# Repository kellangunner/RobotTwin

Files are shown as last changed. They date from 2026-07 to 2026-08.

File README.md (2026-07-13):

# RobotTwin

Digital twin of a 3-DOF desktop robotic arm (base yaw · shoulder pitch · elbow pitch),
designed to be 3D-printed on a Bambu Lab A1 Mini and driven by NEMA 17 steppers through
printed planetary/cycloidal gearboxes.

**Design stance:** linkage geometry is fixed and validated for printability
([docs/linkage-geometry.md](docs/linkage-geometry.md)); the **gearboxes are the independent
variables**. The interactive twin exists to answer: *which reduction, at what efficiency and
backlash, makes this arm work?*

## Quick start

```
cd web
npm install
npm run dev     # interactive twin at http://localhost:5173
npm test        # kinematics / drivetrain / trajectory unit tests
```

Pick each joint's drive type (direct 1:1 / planetary / cycloidal) and reduction ratio in the
left panel — efficiency, backlash, and torque caps are derived from the type — and watch torque
budgets, TCP backlash error, speed limits, move durations, and skipped-step predictions react.
Command poses via Cartesian target (analytical IK, elbow-up/down) or joint sliders.

## Layout

| Path | Contents |
|---|---|
| `config/robot.yaml` | Single source of truth for all robot parameters (SI-converted on load) |
| `docs/` | Decision records & subsystem docs |
| `src/` | **C++20 core library** — kinematics, drivetrain, dynamics, planning, collision ([docs](docs/cpp-core.md)) |
| `tests/` | Native C++ test suite (CMake/ctest), mirrors the web core's fixtures |
| `web/` | Interactive digital twin — React + React Three Fiber (math mirrors `src/`, WASM swap pending) |
| `cad/` *(planned)* | Fusion 360 generation scripts driven by the same YAML |

Build the C++ core:

```
cmake -S . -B build -G "Visual Studio 17 2022" -A x64
cmake --build build --config Release
ctest --test-dir build -C Release
```

See [CLAUDE.md](CLAUDE.md) for the full project charter and roadmap, and
[docs/digital-twin.md](docs/digital-twin.md) for the twin's architecture, equations, and
limitations.

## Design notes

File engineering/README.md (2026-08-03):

# Engineering — CAD generation

CAD is downstream of simulation: link geometry comes from
[config/robot.yaml](../config/robot.yaml) (90 / 120 / 120 mm, frozen per
[docs/linkage-geometry.md](../docs/linkage-geometry.md)); this folder turns it
into printable rigid members.

## Layout

```
engineering/
  fusion/robot_linkages/     linkage generator
    linkage_geometry.py        the parametric layer (pure Python, no Fusion):
                               every dimension, derived joint stacks, and ~50
                               analytic clearance self-checks
    robot_linkages.py          Fusion wrapper: replays the geometry and exports
  fusion/cycloidal_gearbox/  Fusion script that generates the 15:1 / 20:1 gearboxes
  gearboxes/                 gearbox design doc + per-ratio exports (see its README)
  gripper/                   parallel-jaw gripper: parametric layer + Fusion
                             script + design doc + exports (see its README)
  f3d/                       Fusion archive exports   (generated)
  step/                      STEP exports             (generated)
  stl/                       per-part STL exports     (generated)
```

## Verifying and running the generator

Before (or without) opening Fusion:

```
python engineering/fusion/robot_linkages/linkage_geometry.py   # clearance report
python python/audit_linkages.py                                # swept interference audit
```

The audit poses the assembly through full yaw, shoulder 0–180° and elbow
±150° and grid-samples for solid overlap between the printed members,
purchased hardware (motor bodies, screw heads, clamp bolt, the spinning
drive sleeves) and the reserved gearbox envelopes. Adjacent-link clearance is guaranteed mechanically;
whole-arm world collisions (e.g. folded forearm vs the base at extreme
combined poses) remain the twin's runtime collision layer, per
`collision:` in robot.yaml.

Then, in Fusion: UTILITIES → ADD-INS → Scripts and Add-Ins → Scripts → "+" →
select `engineering/fusion/robot_linkages/` → Run. It re-runs the self-checks
(refusing to build if any fail), creates a new Direct-Modeling design, and
writes `f3d/rt-arm-3dof_linkages.f3d` plus one STEP and one STL per part.

## The five printed members

| Part | Role | Bounding (mm) |
|---|---|---|
| `rt_base_pan` | Stationary base: hanging NEMA 17 mount + yaw bearing boss | Ø140 × 59 |
| `rt_shaft_coupling` | Printed coupling (base only): Ø25 bearing journal → Ø28 D-bore pinch body → bolt face. A standard part with its own STEP | Ø28 × 18 |
| `rt_yaw_column` | θ₁ output: low plate bolted to the coupling, clevis ears up to the shoulder axis (z = 90), gearbox mounting face | 76 × 68 × 76 |
| `rt_upper_arm` | Twin-beam clevis: shoulder hub → central beam → web → side beams → elbow clevis (axes exactly 120 mm apart) | 173 × 52 × 76 |
| `rt_forearm` | Elbow hub → beam → gripper interface plate; outer plate face is the TCP plane | 135 × 40 × 40 |

## Base: direct drive with a supported yaw axis

The base joint is driven directly by its NEMA 17 — no gearbox (the yaw axis
fights no gravity torque; the twin's torque governor paces yaw moves).

The motor is a 17HS4401 (42.3 sq × **40** long, 5 mm D-shaft ~23.5 mm): it
**hangs from the pan's 4 mm top plate** (inserted through the floor opening,
body floating above the floor — any 38–42 mm body fits), face bolted to the
plate's underside at z = 46. The arm's weight and overturning moment do
**not** ride on the bare motor shaft. Stack, bottom to top:

1. **Ø25 journal** (z 50.5–58.5) at the *bottom* of `rt_shaft_coupling`; the
   **6805-2RS (25×37×7)** slides on from this end and seats in the pan boss
   (outer race on a ledge at z 51.5, driver-access notches over the four
   motor screws double as head room).
2. **Ø28 pinch body** (z 58.5–69.5): printed D-bore for positive torque
   drive plus a split pinch squeezed by one M3 cross-bolt with a captured
   nut — *above* the bearing, so it is tightened after the coupling is on
   the shaft. Its bottom shoulder presses the bearing's inner race; weight
   goes body → inner race → outer race → boss, and the 6805 pairs with the
   motor's front bearing to resist moment as a spaced couple.
3. The **column plate** (Ø68 × 5) bolts down with 4 × M3 through counterbored
   holes into heat-set inserts in the coupling's top face. Everything on the
   column side near the yaw axis stays below z = 74.5 so the upper arm's
   shoulder hub swings clear through the full 0–180° shoulder range — this
   ceiling is what sizes the Ø30 hub (no hardware protrudes from it since
   the pinch clamp is gone).

The shoulder's drive-side ear disc reaches down to z = 52 and orbits the
stationary boss as the base yaws; the column carries two revolved relief
cuts (Ø47 to z 60.4, Ø52 to z 54.5) that keep it clear of the boss and the
motor screw heads while sparing the gearbox flange seat.

## Pitch joint architecture (shoulder and elbow identical)

- **Live shaft** (this rev, v5): the **8 mm shaft IS the torque path** and
  spins with the driven link. It stays a smooth rod — no flats, same
  68 mm cut as the dead-axle rev, so existing shafts are reused — and is
  grabbed at both ends by press/slip bores closed with **split pinches**
  (the base coupling's proven slit + M3-cross-bolt + captured-nut
  pattern).
- **Torque** flows: gearbox output → its **shaft-clamp extension** (Ø24.6
  pinch past the lid face) → shaft → the **arm hub's own pinch** (Ø30
  boss, slit on the −X side, two M3 cross-bolts) → arm.
- **Bearings live in the ears** now, not the hub: the +Y ear houses a
  **608** (outer race in a Ø22.2 pocket behind a Ø16 lip, inner race on
  the shaft); the drive ear houses a **6805** (Ø37.3 pocket from the
  gearbox face) riding the output extension's Ø25.05 seat. Structural
  loads still go through rolling bearings only.
- **Asymmetric clevis**: the drive ear sits at y 23.5–35.5 (9.75 mm
  further outboard than the +Y ear) so the output's pinch section has
  open tool access in the gap between ear and hub. The gearbox mounting
  face, Ø66 insert BCD, and M3 × 40 through-bolts are unchanged.
- **Axial retention**: both pinches fix the shaft; the +Y collar remains
  as a keeper snugged ~0.5 mm off the ear face (it must not rub the ear).
- **Torque-capacity caveat**: a pinch on smooth hardened rod is a
  friction joint. Degrease the shaft, torque the pinch bolts firmly, and
  treat slip under reversing loads as a real possibility — a drop of
  retaining compound (Loctite 638) in each bore is cheap insurance. This
  is the same interface the v2 design retired; it returns by explicit
  decision, traded for a serviceable joint that matches the purchased
  shaft stock.
- **Gearbox mounting face** (no enclosed drum — v1's drum could never admit
  the cartridge): the drive-side ear is a Ø76 disc whose outboard face
  carries **6 × M3 heat-set inserts on a Ø66 bolt circle**. The cycloidal
  cartridge (Ø76 × 36, see [gearboxes/README.md](gearboxes/README.md))
  bolts on with M3 × 40 through-screws from its back and carries its NEMA 17
  on its own back plate. Cartridge + screw heads + motor are audited as
  keep-out envelopes.
- The upper arm is a **twin-beam clevis**: the central beam ends at a
  derived hand-off station (x ≈ 62 for 120 mm links), a full-width web
  bridges to two side beams flanking the forearm's swing plane, and the
  forearm folds *between* them — this is what makes the full ±150° elbow
  range mechanically reachable (a single mid-plane beam cannot coexist with
  a forearm folded 150°).

## Fasteners

M3 everywhere. Every joint where a part bolts **to a printed member** gets
Ø4.6 × 6.5 pockets for **M3 × 5.7 heat-set inserts** (coupling top face ×4,
gearbox faces ×6 each, gripper plate ×4). Screws into a motor's own tapped
holes (NEMA mounts) and the table-mount holes are plain Ø3.4 clearance; the
base coupling's pinch bolt runs against a captured nut (the only pinch
left — the hub pinches died with the dead-axle rev).

## Gripper interface (forearm tip)

The 12 mm end plate's outer face is the TCP plane and the gripper's
mounting face (see [gripper/README.md](gripper/README.md)): a Ø10.5
through-bore on the TCP centerline registers the gripper's pilot boss and
passes its wiring (a bottom-edge notch feeds the harness under the beam),
and **4 × M3 heat-set inserts on a Ø16 BCD open on the OUTER face** — the
gripper's back plate bolts straight on with M3 × 8. (The earlier
inner-face insert pockets and T8-nut recess sat unreachable under the
forearm beam; the v2 gripper is SG-90 rack-and-pinion driven and uses no
screw hardware at all.) The fingertips reach `gripper_extent_mm` beyond
the TCP plane in the twin's collision model.

## Purchased hardware (BOM)

| Item | Qty | Where |
|---|---|---|
| 608 bearing (8×22×7) | 2 | one per +Y ear, inner race on the live shaft |
| 6805-2RS bearing (25×37×7) | 3 | yaw support + one per drive ear (on the gearbox output's seat) |
| 8 mm hardened steel shaft, cut to 68 mm | 2 | LIVE torque shafts — still smooth, no flats; both ends pinch-clamped (see docs/BOM.md) |
| 8 mm shaft collar | 2 | one per pitch joint, +Y keeper (snug 0.5 mm off the ear) |
| M3 × 20 + nut | 4 | arm-hub pinch bolts, two per hub |
| M3 × 16 + nut | 2 | gearbox-output pinch bolts, one per output |
| SG-90 micro servo | 1 | gripper actuation (lantern pinion + hobbed racks) |
| NEMA 17 17HS4401 (42.3 sq, 40 long) | 3 | one per joint, per config |
| M3 × 5.7 heat-set inserts | 20 | coupling (4), gearbox faces (2×6), gripper plate (4) — the gripper body adds its own |
| M3 nuts | 1 | coupling pinch cross-bolt |
| M3 screws | — | all connections |

## Assembly order

Motor in from below → face screws through the boss notches → pan to table →
6805 into the boss pocket → coupling (journal down) through the bearing onto
the D-shaft → tighten its pinch bolt → column plate bolted down into the
coupling's inserts → 608 pressed into the +Y ear, 6805 pressed into the
drive ear's outboard pocket → arm between the ears, shaft in from the +Y
side through the ear 608 and the hub bore (hub pinch loose) until ~10 mm
protrudes past the hub on the −Y side → gearbox cartridge (bench-assembled,
motor on its back) offered up: its extension slides through the drive-ear
6805 and its bore swallows the shaft end; 6 × M3 × 40 from the gearbox back
into the ear-disc inserts → tighten the OUTPUT pinch bolt (tool access in
the ear-to-hub gap), then the two HUB pinch bolts, then the +Y collar
0.5 mm off the ear face. Every fastener is reachable at its step.

## Assumptions and limitations

- Direct-modeling generator: no Fusion timeline; `linkage_geometry.py` is the
  parametric layer (geometry read from `robot.yaml` at run time) and refuses
  to build if any clearance self-check fails.
- No fillets/chamfers yet — add stress relief at the beam-to-ear transitions
  before printing structural versions.
- The gearbox interface (Ø76 face, Ø66 bolt circle, 6805 pocket, extension
  diameters, pinch length) is a mirrored contract with
  `cycloidal_gearbox.py` — the `GBX_*` constants here and the `ext_*` yaml
  keys there must move together.
- The pinch-on-smooth-shaft couplings are friction joints; their torque
  limit is unproven and lower than the retired sleeve-flat form lock (see
  the gearboxes README's open issues and the caveat above).
- Print settings assumed by the mass model: PETG, ~30 % infill.

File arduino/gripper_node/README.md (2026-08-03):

# Gripper node

An Arduino Uno driving the SG-90 parallel-jaw gripper, independent of the ESP32
that runs the arm.

## Why it is a separate board

The gripper was always the least-coupled subsystem in the robot — no kinematics,
no trajectory, no homing, no torque governor, no place in the firmware's state
machine. Giving it its own MCU therefore costs almost nothing and buys three
things:

- **Power isolation.** A stalled SG-90 pulls ~650 mA. That is precisely the
  transient that browns out a board generating step pulses, and it was already
  the documented brown-out risk on the shared 5 V rail.
- **Correct logic levels.** An SG-90 expects ~5 V pulses. The ESP32 drives
  3.3 V — it works, but with no margin. The Uno's 5 V output is right.
- **A timing consumer removed** from a board running a 1 kHz step engine.

## Two ways to command it, last one wins

- **The knob on A0.** Needs no computer at all, which is what makes it the
  calibration tool. It only takes control once it moves past a small deadband,
  so ADC jitter cannot silently steal the jaws back from a running script.
- **`G <mm>` / `GRIP <mm>` / `R` on either serial port.** USB from a host, or the
  one-way relay from the ESP32 so a scripted move can grip mid-sequence. A
  command re-anchors the knob and takes control back from it.

The onboard LED is solid while the jaws hold, blinks while they move, and is off
when the servo is slack.

Nothing is driven at power-on. The jaws are only *assumed* to sit at
`boot_opening_mm`, so the first deliberate command is what energizes the servo —
that way a power-on cannot lurch the mechanism.

## Where the numbers come from

None of the calibration lives in this sketch. `scripts/gen_gripper_config.py`
reads the `gripper:` block of `config/firmware.yaml` before every build and
emits `src/gripper_config_gen.hpp`, so a pulse-width change is a config edit plus
a reflash — never a code change.

The slew limiting and the opening → pulse-width mapping are not written here
either. They come from `rt::GripperAxis` in `src/hardware/gripper.cpp`, compiled
straight out of the repo core — the same class the twin, the native tests, and
the ESP32 use. That is deliberate: the ESP32 predicts when the jaws land without
ever hearing back from this board, which only works because both run identical
math on identical numbers.

## Pins

| Pin | Function |
| --- | --- |
| D9  | Servo signal (orange). Must be D9 or D10 — the `Servo` library owns Timer1 |
| A0  | Potentiometer wiper; the pot's ends go to Uno 5 V and GND |
| D2  | `SoftwareSerial` RX ← ESP32 GPIO 13 through 1 kΩ |
| D3  | Reserved. Unwired — a future return path would use it |
| D13 | Onboard status LED |
| USB | Host: power, uploads, and the console at 115200 |

D2 rather than D0 because the Uno's hardware UART is wired to its USB chip;
putting the relay there would fight the console and break sketch uploads.

Servo power is a bench supply at 5.0 V with a 1 A limit, with a 470–1000 µF
electrolytic at the servo connector. It shares only a ground with the Uno and
the ESP32. Full wiring, including what not to do with the Uno's barrel jack, is
in [docs/wiring-and-bringup.md](../../docs/wiring-and-bringup.md).

## Build

```bash
pio run -t upload
```

```bash
pio device monitor
```

Commands at the console: `G <mm>`, `GRIP <mm>`, `R`. Traffic arriving on the
relay link is echoed here too — with a one-way link, that echo is the only
evidence the ESP32 is reaching this board.

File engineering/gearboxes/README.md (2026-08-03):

# Cycloidal gearboxes — 15:1 and 20:1 (v3 pinned casing, v5 live-shaft output)

Single-stage cycloidal reducers for the pitch joints (shoulder, elbow): a
**plain Ø76 × 36 mm casing in two flat printed halves** — a *cup* (motor
plate + outer wall) and a *lid* (the mounting flange) — **held together and
registered by the Ø6 × 25 steel ring dowels themselves**, which run through
the entire cup and seat in blind holes in the lid. Six M3 × 40 screws from
the gearbox back clamp cup + lid + linkage ear in one stack: they are the
case closure *and* the mounting. The lid face bolts to the linkage's
drive-side ear disc (Ø76, 6 × M3 heat-set inserts on a **Ø66 bolt
circle**). Since the live-shaft rev (v5) the 8 mm joint shaft IS the torque
path: past the lid face the output's Ø22 hub becomes the **shaft-clamp
extension** — a Ø25.05 seat carrying the drive ear's **6805** support
bearing, then a Ø24.6 **split pinch** that clamps the smooth shaft, whose
other end the arm hub grabs with its own pinch. Only the OUTPUT changed for
v5: **cup, lid, discs, cam, and pins are identical to the dead-axle prints —
do not reprint them.** Both ratios share every dimension except the disc
lobe count and cam eccentricity, so the twin's gearbox trade study
(`gearboxes.shoulder.ratio` in [config/robot.yaml](../../config/robot.yaml))
maps 1:1 onto hardware swaps.

**Single source of truth:** every design-specific number lives in
[gear_parameters.yaml](gear_parameters.yaml). The Fusion generator
([engineering/fusion/cycloidal_gearbox/](../fusion/cycloidal_gearbox/)) and
the validator (`python/validate_cycloid.py`) both parse it — edit the yaml,
re-run both, never edit constants in the scripts.

## Why v3 (the v2 print failed)

v2's monolithic housing was clever and unprintable-in-practice: necked
body, groove-wrapped pins, a pinch clamp fed through a wall tunnel — and
the discs jammed ("too large") because the 0.15 mm profile clearance
vanished under real FDM tolerances. v3 is the simple version:

| | v2 (monolith) | v3 (pinned sandwich) |
|---|---|---|
| Casing | one Ø62/Ø59 necked body, hairline OD slits | two flat Ø76 halves, no supports-critical features |
| Ring dowels | grooves wrapped past the pin equator | free-standing, **through the cup + 6.5 mm into the lid**, double shear, fully captive |
| Case closure | — (monolith) | the ring dowels register the halves; the 6 mount screws clamp them |
| Mount screws | M3 × 10 at the flange, hex key threaded past the body | M3 × 40 through-bolts from the back — nothing to sneak past |
| Disc-to-box fit | 0.9 mm to a grooved ring bore | **4.4 mm to a plain Ø62.5 interior** — the box cannot bind the disc |
| Profile clearance | 0.15 mm (jammed as printed) | **0.25 mm, yaml-tunable**, plus a numeric assembled-mesh sweep in the validator |
| Shaft coupling | split pinch + captured nut + access tunnel | **drive sleeve**: the output's flats plug straight into the arm hub — the shaft is a static, torque-free axle (no flat, no grub screw, no pinch) |
| Parts per gearbox | 4 printed | 5 printed, every one trivial to print |

## How it works

Fixed-ring, rotating-output cycloidal drive. Ratio = Zc (lobes), reversing:

1. The motor's 5 mm D-shaft spins the **eccentric cam** (`rt_cyc*_cam`): two
   Ø15 journals offset ±e, 180° apart, each carrying a **6802-2RS** bearing.
2. Two identical **cycloid discs** (`rt_cyc*_disc`, clocked half a lobe
   apart) wobble on the bearings; their lobes walk around **Zp = Zc + 1
   Ø6 × 25 steel dowel pins** standing free between the casing halves —
   pressed through the cup's bottom (flush at the back face), located in
   the lid's blind holes, loaded in double shear. The pin pattern is
   clocked (11.25° / 0°) so the cup's press holes clear the NEMA screws.
3. Per cam revolution each disc creeps back one lobe pitch: rotation −1/Zc.
   Six more **Ø6 × 25 dowels** pressed 11.7 mm into the **output flange**
   (`rt_cyc*_output`) ride in oversized disc holes (Ø = pin + 2e + 0.3) and
   carry the slow rotation out. The flange's Ø22 hub passes out through
   the lid's Ø25.85 face bore — sized so the **whole extension assembles
   through it** — and continues past the lid face as the **shaft-clamp
   extension**: first a Ø25.05 seat that rides the **6805 bearing housed
   in the drive ear** (this carries the joint's −Y structural load), then
   a Ø24.6 body ending in a **split pinch** — slit open at the tip, one
   M3 cross-bolt with a captured nut — that clamps the live 8 mm shaft.
   The shaft slips ~19.5 mm into the extension's Ø8.35 bore; torque goes
   output → pinch → shaft → the arm hub's own pinch. The drive-ear 6805,
   not the lid, locates the output radially.

Two discs on opposite eccentrics balance the wobbling mass and split the
tooth load; the disc profile is the exact conjugate envelope of the pin set
(generated by simulated hobbing in the Fusion script).

## Parameters

Shared: pin circle R = 28, every pin a Ø6 × 25 steel dowel, disc thickness
6, disc bore Ø24.2 (6802 OD + 0.2), output pins on a Ø36 BCD, profile print
clearance 0.25 mm radial (yaml: `profile_print_clearance` — tune on a test
disc), casing Ø76 with a Ø62.5 interior.

**Steel-pin hole fits are printer-specific — calibrate them.** FDM prints
holes undersize, by an amount that depends on your machine, material, speed,
and cooling, so the pin-hole diameters are modeled *over* nominal to
compensate and are yaml parameters, not fixed numbers
(`external_pin_hole_clearance`, `output_pin_hole_clearance`,
`ring_pin_lid_clearance`, all diametral, added to Ø6). The defaults aim for
a *slip/light* fit retained with adhesive — the most repeatable result
across printers — not a bare interference press, which is what jammed on the
first attempt. The cam's D-bore on the motor's 5 mm shaft is the same story
and is yaml too (`motor_bore_clearance`, `motor_flat_clearance`) — the Ø5.2
first print needed a hammer. See the calibration step under Printing before
committing a full set of dowels.

| | 15:1 | 20:1 |
|---|---|---|
| Disc lobes Zc / ring pins Zp | 15 / 16 | 20 / 21 |
| Eccentricity e | 1.0 mm | 0.8 mm |
| Trochoid coefficient λ = e·Zp/R | 0.57 | 0.60 |
| Disc root / tip radius | 23.75 / 25.75 | 23.95 / 25.55 |
| Min convex profile curvature (vs Ø6.5 cutter) | 6.6 mm ✓ | 5.0 mm ✓ |
| Assembled mesh clearance (full cam sweep) | 0.25 mm ✓ | 0.25 mm ✓ |
| Radial mesh engagement 2e | 2.0 mm | 1.6 mm |
| Disc output holes (6×) | Ø8.30 | Ø7.90 |
| Output torque @ 0.45 Nm × η 0.60 | **4.05 Nm** | **5.40 Nm** |
| Output speed @ 600 rpm input | 40 rpm (240°/s) | 30 rpm (180°/s) |
| Shoulder gravity margin, 100 g payload (1.17 Nm) | ×3.5 | ×4.6 |
| Shoulder gravity margin, 2 kg payload (5.64 Nm) | ×0.72 ✗ | ×0.96 ✗ |
| Cam bearing load (per 6802, C₀ ≈ 1.27 kN) | ~135 N | ~170 N |
| Peak ring / output pin load (steel) | ~36 / ~75 N | ~37 / ~100 N |

Neither ratio statically holds the 2 kg *maximum* payload at full horizontal
reach — that corner of the envelope stays governed by the twin's torque
governor, exactly the trade the digital twin exists to explore. 20:1 gets
within 4 % of it.

## Axial stack (z from the cup's back face, 36 mm to the mounting plane)

```
z  0.0 -  5.0   cup bottom: Ø22.5 pilot recess (2.2 deep), Ø14 shaft bore,
                4x M3 counterbored from inside (heads z 1.5..4.5),
                Zp x Ø6.1 ring-dowel holes, back-chamfered (flush at z 0)
z  0.0 - 25.0   Ø6 x 25 steel ring dowels: through the cup, 6.5 mm into
                the lid's blind holes — they pin the casing together
z  5.0 - 18.5   cup wall, plain Ø62.5 bore (disc reach Ø53.7: 4.4 mm air)
z  5.5 - 11.5   disc A on cam journal +e (bearing 6802)
z 12.0 - 18.0   disc B on cam journal -e, clocked half a lobe
z  5.7 - 30.7   Ø6 x 25 steel output pins (blind holes end z 30.9)
z 18.5 - 36.0   lid: bore Ø48 to z 31.9 (flange plate spins inside),
                then Ø25.85 face bore (the extension assembles through
                it); face flush on the ear disc
z 19.0 - 31.4   output flange plate Ø46 (motor-shaft pocket to z 26 inside)
z 28.0 - 57.75  shaft bore Ø8.35: slip fit, closed onto the shaft by the pinch
z 31.4 - 36.0   output hub Ø22: spins free inside the lid face bore to z 36
z 36.0 - 43.0   Ø25.05 seat: the drive ear's 6805 rides here (pocket depth 7)
z 43.0 - 57.75  Ø24.6 extension body through the ear's Ø27 shoulder, ending
                in the SPLIT PINCH (z 48.75-57.75: slit open at the tip,
                M3 cross-bolt at z 53.25, captured nut) that clamps the
                shaft in the open gap before the arm hub (face at z 58.5)
```

The motor's shaft (max 25 mm) ends inside the flange plate's Ø8.6 pocket
(ceiling z 26); the live joint shaft enters from the far ear through that
ear's 608 and the arm hub's pinch bore, and its tip stops at z 38.25 —
2.25 mm shy of the lid face, ~19.5 mm deep in the extension bore, fully
covering the pinch. The existing 68 mm shafts are reused unmodified.

## Assembly

1. M3 × 8 from inside the empty cup into the motor's threads (pilot boss in
   the recess). Slide the cam onto the D-shaft; the 6802s press onto its
   journals.
2. Disc A over bearing A, disc B over B — the output-hole pattern self-jigs
   the half-lobe clocking.
3. Seat the Zp ring dowels in the cup holes until flush at the back (a dab
   of adhesive per the calibration note unless you dialled in a true press);
   they thread through the meshed disc valleys — wiggle the discs if one
   hangs. The back chamfer starts them straight.
4. Seat the six output dowels in the flange's blind holes (same fit); feed
   the pin cage through both discs.
5. Lower the lid over the extension and onto the dowel tips (the blind
   holes are the jig). The cartridge is now complete but unclamped.
6. Press the 608 into the +Y ear and the 6805 into the drive ear's
   outboard pocket. Set the arm between the ears and slide the 8 mm shaft
   in from the +Y side, through the ear 608 and the hub's pinch bore
   (pinch loose), until ~10 mm protrudes on the −Y side.
7. Offer the cartridge up to the drive ear: the extension tip (Ø24.6)
   passes through the 6805, its Ø25.05 seat presses lightly into the
   bearing bore, and the Ø8.35 bore swallows the shaft end. Run the six
   M3 × 40 from the gearbox back through everything into the ear-disc
   inserts (snug Ø3.2 holes center the casing). Tighten the OUTPUT pinch
   bolt in the ear-to-hub gap, then the arm hub's two pinch bolts, then
   fit the +Y collar 0.5 mm off the ear face. Degrease the shaft first —
   both couplings are friction clamps.

## Printing (Bambu A1 Mini, PETG, ≥4 perimeters, 50 %+ infill)

**Calibrate the dowel holes first.** Print a scrap coupon with a row of
holes at Ø6.0, 6.1, 6.2, 6.3, 6.4 and try a real dowel in each. Pick the
smallest that accepts the pin with firm hand/light-tap pressure (no
splitting) — that diameter minus 6.0 is your `*_hole_clearance` value; set
the three yaml keys and re-run the generator. The stock values are
print-verified on an A1 Mini: cup and lid press perfectly at +0.10
(bed-face holes shrink only ~0.1 mm); the flange runs +0.15 because its
+0.05 first print was too tight to seat. Note the cam's vertical D-bore
shrinks much more than these bed-face holes — its fit is separate
(`motor_bore_clearance`). If you raise the cup value, the NEMA counterbore
clearance check caps it ≈ +0.27 on the 21-pin ring. If you land on a slip fit, that is fine — a drop of
cyanoacrylate or retaining compound in each hole holds the pin far more
repeatably than a bare press, and the ring pins are captive in the sandwich
regardless. The holes carry a back-face (printed-bottom) chamfer to swallow
the elephant's-foot lip and start the pin straight.

- Cup: back face down, wall up — no supports.
- Lid: mounting face down — the internal Ø25.85→Ø48 step is an annular bridge
  ~4.6 mm up; enable supports for it or accept the bridge (it's a
  non-bearing ceiling).
- Discs: flat, no supports. Print ONE first and confirm it drops over the
  assembled pins and rocks freely — the 0.25 mm profile clearance is
  yaml-tunable if your printer runs tight or loose.
- Cam: bore vertical, no supports. Journals sized Ø15.05 — sand to a light
  press on the 6802s. The D-bore is modeled Ø5.35 with the flat 0.2 proud
  (`motor_bore_clearance` / `motor_flat_clearance`) so it *slides* onto the
  motor shaft — the flat drives, the bore only locates.
- Output flange: plate face down (pin holes open at the bed), sleeve up, no
  supports — the pin holes print at their calibrated Ø with the lead-in
  chamfer at the bed, the drive flats print as clean vertical walls, and
  the Ø2.5 lock pilot is a short horizontal hole that needs no support.

## Purchased hardware (per gearbox)

| Item | Qty | Where |
|---|---|---|
| Ø6 × 25 mm steel dowel pin | Zp + 6 (22 / 27) | Zp casing/ring pins + 6 output drive pins |
| 6802-2RS bearing (15 × 24 × 5) | 2 | eccentric cam journals |
| M3 × 8, socket head | 4 | cup → motor threads (heads inside) |
| M3 × 40, socket head | 6 | through the casing → ear-disc heat-set inserts |

(The 608s, 8 mm axle, outboard collar, and the heat-set inserts belong to
the joint/linkage BOM. The axle is static and torque-free: cut to length,
no ground flat, no grub screw — the drive sleeve couples the output
straight to the arm hub.)

## Open issues (before printing structural versions)

1. **Pinch-on-smooth-shaft torque path is unproven — and it is a friction
   joint, not a form lock.** The 20:1 output can deliver 5.4 Nm; a PETG
   split pinch plus a press bore on polished hardened rod plausibly holds
   a few Nm when fresh and loses preload to plastic creep over time.
   Mitigations, in order: degrease the shaft; torque the pinch bolts
   firmly and re-check after the first sessions; retaining compound
   (Loctite 638) in both bores; and the firmware's torque governor
   (`safety.torque_ceiling`) keeping commanded torque below the static
   ceiling. If slip shows up under direction reversals anyway, the
   fallback is grinding a small flat on each shaft end and reprinting the
   two clamp parts with D-bores — the geometry accepts that without
   moving any other dimension.
2. **Backlash isn't zero.** The 0.25 mm profile clearance + 0.3 mm output
   hole clearance ≈ 0.3–0.6° lost motion at the output; the twin currently
   models cycloidal backlash as 0. Measure on the printed unit and update
   `gearbox_models.cycloidal.backlash_deg`.
3. **Efficiency is a guess.** η = 0.60 comes from the config's printed-drive
   assumption; validate with a torque test before trusting the margins.
4. **Pin-hole fit is printer-specific.** The first print modeled the holes
   *under* Ø6 for an interference press; combined with FDM's own hole
   shrink the steel dowels would not enter. The holes are now modeled over
   nominal and exposed as yaml parameters — calibrate them with a coupon
   (see Printing) and prefer a slip fit + adhesive over a bare press.

## Regenerating

- CAD: run `engineering/fusion/cycloidal_gearbox/` from Fusion (Scripts and
  Add-Ins). Reads gear_parameters.yaml, refuses to build if any derived
  clearance check fails, then exports STEP + STL per part into `15_1/` and
  `20_1/`, plus the `rt-gearboxes_cycloidal.f3d` assembly archive. The
  hobbing boolean pass takes a minute or two.
- Dry run (no Fusion): `python engineering/fusion/cycloidal_gearbox/cycloidal_gearbox.py`
  prints the derived stack and all clearance checks.
- Mesh + profile checks: `python python/validate_cycloid.py` — imports the
  generator (never drifts out of sync) and numerically sweeps the assembled
  disc against the pins through a full cam revolution, so a jam like the
  v2 print shows up here, not at the printer.

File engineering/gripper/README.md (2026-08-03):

# Gripper — parallel-jaw, SG-90 rack-and-pinion (v2, in design)

Two parallel jaws driven by a single SG-90 micro servo through a printed
**lantern pinion** meshing two **hobbed racks** — one integrated into each
jaw slider, above and below the pinion, so one rotation input produces
symmetric open/close. Mounts on the forearm-tip plate. Replaces the v1
NEMA 8 + lead-screw design (kept in git history): the servo drive drops the
part count, the bench ops, the homing switch, and about two thirds of the
mass. Same generator pattern as the linkages and gearboxes:

```
engineering/gripper/
  gripper_geometry.py     the parametric layer (pure Python, no Fusion):
                          every dimension, derived drive-train stations,
                          rack hobbing math, 70 analytic self-checks
  gripper.py              Fusion wrapper: replays the geometry and exports
  gripper_parameters.yaml design parameters (opening, pin gearing, walls)
  *.step / *.stl          per-part exports            (generated)
```

Verify and run:

```
python engineering/gripper/gripper_geometry.py   # clearance report + numbers
```

Then, in Fusion: UTILITIES → ADD-INS → Scripts and Add-Ins → "+" → select
`engineering/gripper/` → Run. It re-runs the self-checks (refusing to build
if any fail), creates a Direct-Modeling design with the printed parts plus a
reference solid for the servo, and writes `f3d/rt-gripper.f3d` plus one STEP
and one STL per printed part into this folder.

## Headline numbers (defaults; all from the yaml)

| Quantity | Value |
|---|---|
| Jaw opening | 0–36 mm (pad face to pad face) |
| Servo swing | ~115° of the SG-90's ~160° usable travel |
| Grip force | ~6.5 N per jaw working (~8.8 N at stall) |
| Self-locking | **no** — keep the servo powered while gripping |
| Reach beyond TCP | 71 mm to the fingertips (v1: 138 mm) |
| Mass estimate | ~56 g (≈39 g printed + ≈18 g hardware; v1: ~165 g) |
| Homing | none needed — the servo is its own absolute reference |

**Twin updates required before this design is accepted** (simulation first —
do not print until the torque budget passes):
`collision.gripper_extent_mm: 140 → 75` and `masses.gripper_g: 170 → 60`
in `config/robot.yaml`, then re-run `python python/validate_cycloid.py` and
check the shoulder margins. The generator prints these numbers on every run.

## Architecture: lantern pinion, two mirrored racks

The gripper is self-contained along the tool axis (x = 0 at the TCP plane,
+X outward, jaws travel in Y, Z up):

```
x:  0    5  8      27.2  30.6 31.6  34.6    41.6  43   52  55       71
    |back|   SG-90 case  |plate|flange|  pins   |  |head|fp | fingers →
    |plate|  (nose +X)   |3.4  | Ø22.5| Ø4.5 x8 |  |tunnel|  | + pads
```

- **Back plate** (part of `rt_grip_body`) bolts to the forearm tip with
  4 × M3 × 8 on the Ø16 BCD, heads sunk in counterbores. A Ø10.3 **pilot
  boss** registers in the plate's Ø10.5 bore; the servo lead exits through
  its Ø7 center hole to the plate's bottom-edge wire notch. **The printed
  forearm is untouched — the v1 mounting contract is byte-identical.**
- **`rt_grip_bulkhead`** — the servo cartridge: the SG-90 is bench-screwed
  nose-first to this plate (its two tab self-tappers into printed Ø1.8
  pilot holes; the nose passes a 13.0 × 23.4 window). The loaded plate
  slides down vertical grooves in the housing walls and the lid captures
  its top edge — the whole drive drops in and out with **zero fasteners
  into the housing**. Grip reaction torque runs tab → plate → wall grooves.
- **`rt_grip_pinion`** — a lantern gear, printed flange-down with no
  supports: Ø22.5 flange + Ø11.4 core press onto the servo's Ø4.8 21T
  spline (Ø4.5 bore broaches on assembly), retained by the servo's own
  horn screw down the core's center bore (driver comes straight down the
  tool axis through the face-plate slot before the jaws go in). Eight
  Ø4.5 × 7 pins on the Ø18 pitch circle are the teeth.
- **Racks**: each jaw slider carries a toothed bar through the housing's
  rack window — `rt_grip_jaw_p` above the pinion, `rt_grip_jaw_n` below.
  Tooth spaces are **hobbed**: the pin-radius cutter (+0.25 mm print
  clearance) is subtracted along the cycloid the pin centers trace in the
  rack's frame — the same simulated-hobbing construction as the cycloidal
  gearbox discs. Pin gearing is exact conjugate action with no undercut;
  a numeric sweep in the self-check suite confirms at least one pin bears
  in each drive direction at every angle of the stroke. Tooth separation
  loads are backed by rails: the floor under the lower rack, a rib hanging
  from the lid over the upper one.
- **Jaws**: transverse carriers in the head tunnel (v1 pattern), necks out
  through the face-plate slot, fingers with 1 mm-keyed **TPU pad** pockets
  (`rt_grip_pad`, print 2 in TPU, faces 2 mm proud). Each rack bar reaches
  its carrier through an outer arm past the pin cage and a riser through
  its own passage in the jaw head (top passage for jaw_p, bottom for
  jaw_n).
- **Kinematics**: 9 mm pitch radius × ~2 rad of servo swing = 18 mm of
  stroke per jaw = 36 mm opening. Rack backlash from the 0.25 mm hob
  clearance is ~0.5 mm at the pads — irrelevant for gripping (the servo
  pushes through it), only visible in free positioning.

## Printed parts

| Part | Role | Notes |
|---|---|---|
| `rt_grip_body` | housing: back plate, servo bay, grooves, rack window, jaw head | print upright, back plate down |
| `rt_grip_lid` | top plate + upper-rack rail rib, 6 × M3 × 8 into inserts | print top face down |
| `rt_grip_bulkhead` | servo cartridge plate | |
| `rt_grip_pinion` | lantern pinion | flange down, pins vertical, no supports |
| `rt_grip_jaw_p` / `rt_grip_jaw_n` | jaw sliders with integrated racks | supports under the fingers |
| `rt_grip_pad` × 2 | finger pads | **TPU** |

## Hardware

| Item | Qty | Note |
|---|---|---|
| SG-90 9 g micro servo | 1 | clones fine; pockets carry ±0.3 mm envelope slack |
| M3 × 8 | 10 | 4 mount (into the forearm plate inserts), 6 lid |
| M3 × 5.7 heat-set inserts | 6 | lid pockets in the housing |
| servo tab self-tappers | 2 | supplied with the servo, into printed pilots |
| servo horn screw (~M2 × 8) | 1 | supplied with the servo, retains the pinion |

No lead screw, no flanged nut, no 623 bearings, no microswitch, no NEMA 8 —
and no bench filing/drilling/tapping ops at all.

## Assembly order

1. Bolt the housing to the forearm plate (4 × M3 × 8, ball-end or stubby
   driver — do this FIRST, the heads sit under the servo bay).
2. Bench: screw the SG-90 to `rt_grip_bulkhead` (2 self-tappers), command
   the servo to its jaw-OPEN endpoint (firmware or servo tester), press
   `rt_grip_pinion` onto the spline and drive the horn screw home down the
   core bore.
3. Slide the cartridge down the wall grooves; route the lead down the bay
   and out the pilot-boss hole (through the forearm plate's wire notch).
4. Slide the jaws in from their sides at the OPEN width — the racks mesh
   the pin cage as they enter; fingertip faces should sit 36 mm apart.
   Grease the pins and rack pockets (PTFE or silicone).
5. Lid on (its rib captures the upper rack), 6 × M3 × 8. Press the TPU
   pads into the finger pockets.

Every step is reversible without touching the others: the drive cartridge
lifts straight out once the lid and jaws are off.

## Firmware note

The gripper axis is a **hobby-servo PWM channel** (50 Hz, 1–2 ms), not a
stepper: no driver, no limit switch, no homing move. The v1 plan (step/dir on
13/14, limit on 27) is obsolete.

**It does not run on the ESP32.** An Arduino Uno drives the servo from its own
bench supply (5.0 V, 1 A limit) and the ESP32 relays `GRIP` to it over one wire
on GPIO 13. That closes the "still open" item this note used to carry — the
~650 mA stall transient now lands on a rail of its own instead of the one
generating step pulses — and it gives the servo proper 5 V logic besides.

It is implemented: `gripper:` in `config/firmware.yaml` (read by both boards),
`rt::GripperAxis` (`src/hardware/gripper.cpp`, the shared opening → pulse-width
model, which runs on the Arduino too), `fw::GripperLink` (the relay) and the
`GRIP <mm>` verb. `arduino/gripper_node/` is the Arduino side, and it also takes
a manual knob so the mechanism can be calibrated with no computer attached. The
firmware knows the mechanism only as two calibration pulses and the opening
between them, so the endpoints below must be measured at bring-up — see
docs/wiring-and-bringup.md "Gripper calibration".

## Assumptions and limitations

- **Not self-locking**: the SG-90's plastic gearing holds light grips
  unpowered by friction only. Keep the servo powered while carrying, and
  treat grip force as ~6.5 N per jaw sustained.
- Servo envelope constants assume a standard SG-90/clone (22.8 × 12.4 mm
  case, 27.6 mm hole pitch); measure an odd clone before printing.
- Direct-modeling generator, no fillets/chamfers yet; printed sliding fits
  use 0.35 mm side clearance — tune on the printer before trusting them.
- The swept interference audit lives in this module's own checks (plus the
  numeric mesh-contact sweep); folding the gripper's prismatic DOF into
  `python/audit_linkages.py` is future work, as is the jaw state in the
  twin's collision model (today it is a lumped extent + mass).
- Servo position ↔ jaw opening is linear (18 mm per 2 rad); calibrate the
  two PWM endpoints once at bring-up.

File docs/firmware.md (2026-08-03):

# ESP32 Firmware

## Overview

The firmware makes the physical arm behave exactly like the digital twin: the same C++20 core
library (kinematics, drivetrain, dynamics, planning, retiming, collision) compiled unchanged for
the ESP32, fed by the same two YAML files, running the same plan-time pipeline before any move
reaches a motor. A command the twin would refuse is refused on hardware with the same verdict;
a command the twin would slow down is slowed by the same stretch factor.

Hardware: ESP32 DevKit (WROOM-32) + three TMC2209 drivers in step/dir mode, one shared enable
line, one limit switch per joint, and one SG-90 servo on the gripper. Board wiring lives in `config/firmware.yaml`; the robot itself
in `config/robot.yaml`. Both are baked into the flash image at build time (a generated header — `firmware/scripts/gen_embedded_configs.py`)
and parsed at boot by the same loaders the native tests exercise — a pin change is a config edit
plus reflash, never a code change.

## Architecture

```
firmware/
  components/robottwin_core/   the repository's src/ as an ESP-IDF component + embedded YAMLs
  src/
    main.cpp                   boot order: configs → step engine → TMC2209 → controller → console
    embedded_configs.cpp       flash-embedded YAML → RobotConfig / HardwareConfig
    step_engine.cpp            40 kHz GPTimer ISR, integer DDA per joint (step/dir generation)
    gripper_link.cpp           one-way UART2 relay to the gripper node's Arduino
    motion_controller.cpp      state machine + the twin's planning pipeline + homing
    serial_console.cpp         UART0 line protocol (rt::proto), telemetry, events
    tmc2209.cpp                optional write-only UART config of the drivers
```

Three execution contexts, strictly layered by math weight:

| Context | Rate | Work |
| --- | --- | --- |
| GPTimer ISR (`StepEngine`) | `step_tick_hz` (40 kHz) | integer DDA only: accumulate Q16.16 rate, emit one step toward target, write GPIO registers |
| control task (`MotionController`, core 1) | `loop_hz` (1 kHz) | sample the active quintic, convert to microstep targets + rates, homing state machine |
| console task (`SerialConsole`, core 0) | on demand | parse commands, run the full planning pipeline (IK, metrics, audit, retime, collision) |

Planning never runs in the control loop; the control loop never allocates. Shared state crosses
tasks under a short spinlock, and every control-tick write to the step engine re-checks the mode
under that lock so a STOP can never be overwritten by a tick that raced it. Completion and fault
notifications flow back through a FreeRTOS queue and appear on the wire as `EV` lines.

## Command pipeline (mirrors `web/src/state/store.ts`)

For `MOVEJ` / `MOVEL`:

1. guards — FAULT? busy? drivers enabled? homed?
2. `MOVEL` only: analytic IK, keep limit-respecting collision-free solutions, take the one
   closest to the current pose (same rule as the twin's `pickIkSolution`)
3. `computeMetrics` at the current pose → per-joint `vmax`/`amax`; plan with the twin's 0.8
   speed margin and `safety.min_move_duration_s`
4. `retimeForTorque` against `safety.torque_ceiling` / `safety.max_stretch` — the torque
   governor; a static overload rejects with `ERR TORQUE`
5. `checkPath` over the retimed plan — a colliding path rejects with `ERR COLLISION`
6. install the plan; reply `OK MOVEJ T=<s> STRETCH=<k>`; `EV MOVE_DONE` when settled

State machine: `IDLE → HOMING → IDLE`, `IDLE → MOVING → IDLE`, anything → `FAULT` (homing
timeout, stuck switch). `STOP` halts and clears FAULT; `DISABLE` de-energizes and drops `homed`
(unpowered steppers slip under gravity, so the datum is no longer trustworthy).

## Homing

Two ways to establish the datum; both set `homed` and unlock moves, and both are lost on
`DISABLE`.

**`SETHOME θ₁ θ₂ θ₃` (manual, no switches).** The operator places the arm at a known pose and
declares it: the firmware validates the angles against the joint limits, `setPosition`s each
step counter to them, and marks `homed`. This is the datum path for the arm as designed —
it has no limit switches and no hard stops. Requires `ENABLE` first (drivers must be holding
the placed pose).

**`HOME` (switch-seek, only if switches are fitted).** Joint-by-joint in `homing_order`,
per-joint watchdog `homing_timeout_s`: seek fast toward the switch → back off `backoff_deg` →
re-seek slow → the slow trip is the datum (`setPosition(home_angle_deg)`) → back off again to
release the switch.

Steps are the ground truth thereafter; before the first datum, position 0 is simply the boot
pose and moves are refused with `ERR NOT_HOMED`.

## Gripper axis

The gripper is not a joint. It is an SG-90 hobby servo — a closed-loop actuator in its own right,
told a position and left to hold it — driving the parallel-jaw mechanism at the forearm tip. So it
gets none of the machinery the three joints get: no step/dir, no driver, no trajectory, no torque
governor, no homing, no place in the state machine.

**It does not run on the ESP32.** An Arduino Uno drives the servo from its own 5 V supply and the
ESP32 only relays commands to it over one wire. Two reasons: a stalled SG-90 pulls ~650 mA, which
is precisely the transient that browns out a board generating step pulses, and a hobby servo wants
5 V logic rather than the ESP32's marginal 3.3 V. Because the gripper was already the least-coupled
subsystem here, the split cost one driver class and changed nothing about the protocol.

What it does get:

| Piece | Where | Job |
| --- | --- | --- |
| `gripper:` block  | `config/firmware.yaml` | pins for both boards, PWM rate, the two calibration pulses, stroke, slew speed, boot opening, idle release |
| `rt::GripperAxis` | `src/hardware/gripper.cpp` | opening → pulse width, slew limiting, idle release — pure, shared, unit tested. Runs on**both** boards |
| `fw::GripperLink` | `firmware/src/gripper_link.cpp` | writes`G <mm>` / `R` to UART2; drops repeats so a 1 kHz loop stays off a 19200 baud wire |
| `tickGripper` | `motion_controller.cpp` | runs every control tick in*every* mode, outside the state machine |
| gripper node | `arduino/gripper_node/` | the Uno sketch: servo, manual knob, both serial inputs |

**Both boards slew the same axis.** The ESP32 sends a destination, not a position, and the Uno
gets there on its own — they run identical `rt::GripperAxis` math from identical calibration (the
Uno's copy is baked in at compile time by `gen_gripper_config.py`, since an ATmega328P has no room
for a YAML parser). That agreement is what lets the ESP32 time `EV GRIP_DONE` and fill in `grip=`
without ever hearing back over the one-way link.

**The model is two points.** `closed_pulse_us` is 0 mm, `open_pulse_us` is `max_opening_mm`, and
opening is linear between them — which is what a rack-and-pinion (or an equivalent geared parallel
linkage) gives over its usable swing. The firmware knows nothing else about the mechanism, so a
`GRIP` distance is only as true as that calibration.

**Commands slew, they don't jump.** `GRIP <mm>` is rate-limited to `speed_mm_s`, so a full-stroke
command neither flings the mechanism nor browns out the servo's rail; `EV GRIP_DONE` reports the
landing. `GRIP` is accepted in `IDLE` *and* `MOVING` (the axes are mechanically independent, so a
script can approach and close in one breath) and needs no datum — but it does need `ENABLE`, which
is what starts relaying to the Uno, and `FAULT` blocks it like everything else.

**`STOP` and `FAULT` freeze the jaws where they are** rather than opening them: dropping the part
is the worse failure. `DISABLE` cuts the servo drive along with the steppers — nothing on the robot
stays energized after it.

**It is open-loop, and more blindly so than the steppers.** There is no step counter to reason
from: the firmware reports the opening it commanded. On boot (and after `DISABLE`) it simply
believes `boot_opening_mm`, so park the jaws there before powering up or the servo will snap to it
on `ENABLE`. `release_after_s` stops the drive after that many seconds of stillness to silence the
holding buzz — the mechanism is not self-locking, so it defaults to 0 (drive forever).

**Two things the split costs.** The link is one wire and a shared ground with nothing coming back,
so the ESP32 cannot tell whether the Uno is powered, listening, or even connected — a `GRIP` that
reports `OK` may have gone nowhere. During bring-up, watch the Uno's own USB console, which echoes
everything it receives. And turning the Uno's manual knob mid-script moves the jaws without the
ESP32 knowing, leaving `grip=` stale until the next `GRIP` re-synchronises it.

## Step generation

One GPTimer ISR services all three joints with an integer DDA: per tick a channel accumulates
its Q16.16 rate and on overflow emits one step toward its target — position can never overshoot,
and the max step rate equals `step_tick_hz`. The control loop feeds absolute microstep targets
plus a tracking rate (sampled |q̇| × 1.25 + 50 steps/s so quantization never outruns the DDA).
Conversion is `steps/rad = 1 / jointResolution(motor, gearbox)` from the shared drivetrain model.

## TMC2209 UART (enabled)

This build runs `tmc_uart.enabled: true`: boot pushes GCONF (UART current control, MRES from
register), CHOPCONF (microstep resolution from `robot.yaml motor.microstepping`) and IHOLD_IRUN
to each strap-addressed driver over the shared single-wire UART (GPIO26 through a 1 kΩ resistor
to the bussed PDN_UART pins; MS1/MS2 are the address straps — base 0, shoulder 1, elbow 2).
Motor current therefore comes from `firmware.yaml` `irun`/`ihold`, not the VREF pots, and a
current change is a config edit + reflash. Write-only — nothing is read back; step/dir remains
the only motion path. If disabled, the MS1/MS2 straps revert to microstep-select and must match
`robot.yaml` by wiring.

## Building

Wiring and first-power-on instructions live in [wiring-and-bringup.md](wiring-and-bringup.md).

```
cd firmware
pio run              # build (PlatformIO, espressif32 + ESP-IDF)
pio run -t upload    # flash
pio device monitor   # the protocol console at 115200 baud
```

Typical bring-up session:

```
PING            → PONG rt-arm-fw 0.1.0
ENABLE          → OK ENABLE
HOME            → OK HOME … EV HOMING elbow … EV HOMED
MOVEJ 0 90 -90  → OK MOVEJ T=1.204 STRETCH=1.00 … EV MOVE_DONE
GRIP 0          → OK GRIP … EV GRIP_DONE
TELEM 10        → OK TELEM + ST lines at 10 Hz
```

## Assumptions

- The arm is racked roughly upright at power-on (elbow homes first; see `firmware.yaml`).
- Limit switch angles/directions are bring-up placeholders until measured on the real arm.
- Open-loop steppers: the torque governor plus the audit's skipped-step prediction are the only
  defenses against lost steps; there is no encoder feedback.
- step/dir/enable pins < GPIO32 (the ISR writes the low GPIO bank's set/clear registers).
- The gripper's jaw opening is linear in servo pulse width between the two calibration points, and
  the jaws are physically at `boot_opening_mm` when the board powers up.

## Limitations / next steps

- No host-side `HardwareRobot` backend yet — the protocol codec (`src/hardware/serial_protocol`)
  is shared and round-trip tested, so the twin can grow a WebSerial/`IRobot` client next.
- Homing values and TMC current scales need tuning against real hardware.
- `EV` lines carry no timestamps; add them if trajectory tracking needs offline analysis.
- The gripper calibration in `firmware.yaml` ships deliberately conservative (1200–1800 µs over
  a nominal 30 mm) so a first power-on cannot stall the servo against a hard stop. Widen it and
  measure the real opening before trusting `GRIP` distances.
- The gripper is open-loop and unsensed: the firmware reports the opening it *commanded*, and a
  slipped, obstructed, or backdriven jaw looks identical to a successful grasp. Closing on a part
  is what `PAYLOAD` is for — the torque governor is not told about it automatically.

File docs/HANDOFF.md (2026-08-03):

# RobotTwin — Bring-Up Handoff

**Date:** 2026-07-21
**Phase:** 6 (physical bring-up), in progress
**Scope of this doc:** the live work — getting firmware onto real hardware and
the arm moving. The software twin, C++/WASM core, and CAD are done; see
[CLAUDE.md](../CLAUDE.md) for the full project vision and the per-subsystem
docs for their details.

---

## TL;DR — start here

The firmware is finished and **proven on real hardware** — it built, flashed to
an ESP32, and answered `PING` → `PONG` over serial, with the embedded YAML
config parsing correctly on-chip. The blocker is **wiring the bench rig**. The
first dev board was killed by a wiring fault the instant a LiPo was connected
to a hand-wired breadboard. A new **hole-by-hole wiring guide with multimeter
verification gates** now exists specifically to prevent a repeat.

**To resume:** get a replacement ESP32 + a multimeter + an inline fuse, set
`irun: 12` for breadboard use, reflash, then build the rig by following
[breadboard-step-by-step.md](breadboard-step-by-step.md) top to bottom —
**do not skip Gate 1 and Gate 2.**

---

## Project state at a glance

| Layer | State |
|---|---|
| Web digital twin (`web/`) | ✅ Done — FK/IK, drivetrain, torque governor, collision, trajectories, 58 tests pass |
| C++20 core (`src/`) + WASM | ✅ Done — mirrors the twin, native tests pass, WASM drives the web app |
| Firmware (`firmware/`) | ✅ **Builds green + flash-proven on hardware** (this session) |
| CAD / mechanical | ✅ Frame, bearings, shafts ready to assemble (per owner) |
| **Physical bring-up** | 🔧 **IN PROGRESS — blocked on bench wiring** (dead board, rebuild pending) |

---

## What's proven (don't re-verify)

- **Firmware builds green** with PlatformIO (espressif32 6.13.0 / ESP-IDF
  5.5.3). Footprint: **Flash 52.5%, RAM 5.7%**. Full clean build from scratch
  produces `firmware.bin`.
- **First hardware flash succeeded.** `pio run -t upload` → board boots →
  serial console emits `EV BOOT rt-arm-fw` → `PING` returns
  `PONG rt-arm-fw 0.1.0`.
- **The embedded config parses on-target.** That clean `EV BOOT` (no panic, no
  reboot loop) is the runtime proof that `config/robot.yaml` + `firmware.yaml`
  are correctly baked into flash and parsed by the on-board loaders.

The whole software chain — build → flash → boot → config → console — is
validated on real silicon. **A replacement board reflashes to this exact state
in ~10 minutes.**

---

## This session's changes — ⚠️ UNCOMMITTED

The working tree has meaningful uncommitted changes. **Decide whether to commit
before continuing** (kept uncommitted so far by owner preference). All changes
are isolated to firmware + docs; nothing touched the twin, core, or CAD.

### Firmware build fix (the reason the firmware now builds under PlatformIO)

The original firmware embedded the YAML via ESP-IDF's `EMBED_TXTFILES` in a
component `CMakeLists.txt`. PlatformIO's SCons build mis-maps the generated
`robot.yaml.S` into a **doubled build path**
(`.pio\build\esp32dev\.pio\build\esp32dev\robot.yaml.S.o` → "Source not
found") — so the firmware had never actually built under PlatformIO despite
being assumed to. Replaced with a build-time code generator:

| File | Change |
|---|---|
| `firmware/scripts/gen_embedded_configs.py` | **New.** Pre-build hook: reads `config/*.yaml` → writes `src/embedded_yaml_gen.hpp` (`kRobotYaml`/`kFirmwareYaml` raw-string literals). |
| `firmware/platformio.ini` | Added `extra_scripts = pre:scripts/gen_embedded_configs.py`. |
| `firmware/src/embedded_configs.cpp` | Uses the generated header instead of `asm("_binary_*")` symbols. |
| `firmware/components/robottwin_core/CMakeLists.txt` | Removed `EMBED_TXTFILES`. |
| `firmware/src/embedded_configs.hpp` | Comment updated. |
| `firmware/.gitignore` | **New.** Ignores `.pio/` (was NOT ignored — the whole build tree was committable) and the generated header. |

Same single-source-of-truth: the twin's YAML is still baked into flash,
regenerated every build. A pin change is still a config edit + reflash, never a
code change.

### Documentation

| File | Change |
|---|---|
| `docs/breadboard-step-by-step.md` | **New.** Hole-by-hole guide for the owner's specific bench (see below). |
| `docs/breadboard-wiring.md` | Cross-link added; corrected the "two PDN pads are tied" line for split TX/RX carriers. |
| `docs/wiring-and-bringup.md` | Cross-link added; corrected a wrong claim that the 30-pin ELEGOO lacks GPIO16/17. |
| `docs/firmware.md` | `EMBED_TXTFILES` reference updated to the generated-header mechanism. |

---

## The hardware incident (what to learn from, not repeat)

- **What died:** an ELEGOO ESP32 DevKit V1 TypeC (CP2102 USB-serial). It still
  powers its LED but **enumerates zero COM ports** — the USB-serial chip is
  fried; the board is dead as a controller.
- **When:** the instant a **3S LiPo (~11.45 V, used as the motor supply)** was
  connected to a hand-wired breadboard rig.
- **Why (best hypothesis, never traced):** motor voltage reached the 3.3 V
  logic side — most likely LiPo onto a logic net / VIN, or a missing/faulty
  common ground. The rat's-nest wiring made an autopsy less reliable than a
  clean rebuild, so a rebuild was chosen.
- **The lesson, now baked into the guide:** the two most dangerous mistakes are
  (1) motor voltage bridging to the 3.3 V rail / VIN, and (2) reversed VM
  polarity. The new guide's **Gate 1** (cold multimeter check: *VM ↔ 3V3 must
  be open*) and **Gate 2** (staged power-up with drivers removed for first
  battery contact) exist to catch exactly these before anything expensive is at
  risk.

---

## Immediate next steps (in order)

1. **Acquire hardware:**
   - Replacement ESP32 — ELEGOO DevKit V1 TypeC, or any 30-pin WROOM-32 with
     the same labels (the guide's rows are locked to this board).
   - **Multimeter** (required — the verification gates depend on it).
   - **Inline fuse holder + 3–5 A fuse** for the LiPo + lead.
   - A **data** USB-C cable (not charge-only) — a brand-new board that shows no
     COM port is almost always the cable.
   - Confirm on hand: 3 × 100 µF ≥35 V caps, 1 × 1 kΩ resistor, 22 AWG
     solid-core jumpers.
2. **Set breadboard current:** edit `config/firmware.yaml` → `tmc_uart.irun:
   12` (down from 16; the breadboard ceiling is ≤ 0.8 A). Rebuild + reflash.
   **Restore `irun: 16` only when the rig graduates to soldered wiring.**
3. **Rebuild the rig** strictly per
   [breadboard-step-by-step.md](breadboard-step-by-step.md). Strip the boards
   bare first. **Do not skip Gate 1 (cold check) or Gate 2 (staged power).**
4. **Bring-up procedure** (from
   [wiring-and-bringup.md](wiring-and-bringup.md)): smoke test (`PING`) →
   `ENABLE` and feel each shaft lock → `SETHOME` manual datum (this arm has
   **no limit switches**) → first `MOVEJ` / `MOVEL`.
5. **Then** couple to the arm and tune (see watch-outs).

---

## Key commands

```bash
# All from the firmware/ directory, in a terminal where `pio` is on PATH
pio run                 # build (regenerates the embedded config header first)
pio run -t upload       # flash over USB
pio device monitor      # serial console, 115200 baud (--echo to see your typing)
```

Both YAML configs are embedded at build time, so **any change to
`config/firmware.yaml` or `config/robot.yaml` needs a rebuild + reflash** —
never a code change.

---

## File & doc map

| Path | What |
|---|---|
| [docs/breadboard-step-by-step.md](breadboard-step-by-step.md) | **Resume here** — hole-by-hole rig for the dovetailed 2-board bench |
| [docs/breadboard-wiring.md](breadboard-wiring.md) | Board-agnostic net list (electrical source of truth) |
| [docs/wiring-and-bringup.md](wiring-and-bringup.md) | Bring-up procedure, command reference, troubleshooting |
| [docs/firmware.md](firmware.md) | What the firmware does |
| [docs/BOM.md](BOM.md) | Bill of materials |
| `config/firmware.yaml` | Board wiring: pins, UART, current, addresses (**single source of truth for pins**) |
| `config/robot.yaml` | The robot: geometry, gearboxes, limits, motor, collision |
| `firmware/scripts/gen_embedded_configs.py` | Build-time config-embed generator |

**Pin summary** (from `firmware.yaml`): base STEP/DIR = D4/D27, shoulder =
D18/D19, elbow = D21/D22, shared EN = D23, UART TX = D26 (→ 1 kΩ → driver
**RX**, write-only), gripper relay TX = D13 (→ 1 kΩ → Arduino Uno D2; the
SG-90 runs off that separate board, not this one — reserved, not yet
wired on the bench rig). Driver UART
addresses: base 0, shoulder 1, elbow 2 (MS1/MS2 straps).

---

## Open items & watch-outs

- **Uncommitted working tree** — the firmware fix + all docs above. Commit
  decision pending.
- **Bench rig is bench-only.** The 2-board layout shares one motor rail pair
  across all three drivers (only two rail pairs exist), so it's for smoke test
  / hold test / slow unloaded moves. Solder or use screw terminals before
  running the assembled arm.
- **Split TX/RX PDN pads:** the owner's driver carriers break PDN_UART into
  separate TX/RX pads. This build's UART is write-only — wire the bus to **RX**
  only, leave TX empty.
- **Flash-size warning** during build (`Expected 4MB, found 2MB`) is cosmetic —
  app fits fine. Only worth reconciling (`sdkconfig`) if OTA/larger partitions
  are wanted later.
- **Motion-tuning risk (later phase):** the live-shaft pinch joints are
  friction joints on polished rod (~few Nm vs 5.4 Nm available) — see open
  issue 1 in `engineering/gearboxes/README`. Mitigations: degrease + Loctite
  638 + the firmware torque governor. Relevant once moving under load, not for
  electrical bring-up.
- **Doc drift flagged separately:** `docs/firmware.md` still references limit
  switches in one spot (the arm has none) — a background task was spun off for
  it.

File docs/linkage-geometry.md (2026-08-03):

# Linkage Geometry Decision Record

**Status:** Fixed for Phase 2–3. The gearbox parameters are the independent variables of the
digital twin; everything in this document is held constant so that gearbox trade-offs can be
studied in isolation.

## Decision

| Parameter | Value | Notes |
|---|---|---|
| Base height (table → shoulder pitch axis) | **90 mm** | Houses base NEMA 17 (vertical) + base gearbox + 608 thrust path |
| Upper arm (shoulder axis → elbow axis) | **120 mm** | |
| Forearm (elbow axis → TCP) | **120 mm** | TCP = gripper grasp point |
| Maximum horizontal reach | **240 mm** | From base yaw axis |
| Maximum working height | **330 mm** | Arm fully vertical |

### Joint conventions and limits

World frame: Z up, X forward. All angles zero at the reference pose (arm horizontal, straight, pointing along +X).

| Joint | Axis | Symbol | Limits | Notes |
|---|---|---|---|---|
| Base yaw | Z (vertical) | θ₁ | ±135° | Limited for cable routing |
| Shoulder pitch | horizontal, in-plane | θ₂ | 0° … 180° | Measured from horizontal, positive up |
| Elbow pitch | parallel to shoulder | θ₃ | ±150° | 0° = straight arm (workspace-boundary singularity); both elbow-up and elbow-down branches mechanically reachable |

Kinematics (arm plane at azimuth θ₁):

```
r   = L1·cos θ2 + L2·cos(θ2+θ3)
z   = h  + L1·sin θ2 + L2·sin(θ2+θ3)
tcp = (r·cos θ1, r·sin θ1, z)
```

## Why these numbers

**Printability on Bambu Lab A1 Mini (180 × 180 × 180 mm):**

| Part | Bounding size (est.) | Fits? |
|---|---|---|
| Upper arm (120 mm axis-to-axis + 2 × ~24 mm joint housings) | ~168 × 60 × 45 mm | ✔ printed flat |
| Forearm (120 mm + one housing + gripper mount) | ~160 × 55 × 40 mm | ✔ |
| Base housing | ⌀ ~140 × 70 mm | ✔ |
| Cycloidal / planetary gearbox | ⌀ 60–80 mm | ✔ |

Every structural part clears the build volume with ≥ 10 mm margin; no part needs to be split.

**Torque feasibility (worst case, arm straight and horizontal, 100 g payload):**

- Shoulder gravity torque ≈ **1.09 N·m** (link masses + elbow-mounted NEMA 17 + 60 g gripper + payload)
- Elbow gravity torque ≈ **0.26 N·m**
- A NEMA 17 (0.45 N·m holding) needs roughly a **4:1 ratio at ~80 % efficiency just to hold** the shoulder
  at full extension — which is exactly the regime where the gearbox trade study is interesting.
  Ratios from 1:1 (fails) to ~30:1 (slow but strong) all produce meaningfully different behavior.

**Equal link lengths (120/120):** maximizes dexterous annulus volume for a given reach, keeps
IK conditioning symmetric, and lets the upper arm and forearm share bearing/housing designs.

**Shoulder axis intersects base axis (no lateral offset):** keeps the analytical IK exact and O(1)
with no offset compensation term.

## Fixed mechanical assumptions baked into the mass model

- Motors: 3 × NEMA 17, 42.3 × 42.3 × 48 mm, ~350 g, 0.45 N·m holding torque
- Base and shoulder motors live in/near the base; **elbow motor is mounted at the elbow** (its 350 g
  appears at the end of the upper arm in the gravity model — deliberate, so gearbox ratio choices
  are stress-tested against a realistic mass distribution)
- Bearings: 608 (8 × 22 × 7 mm) at every joint; structural loads through bearings, gearboxes transmit torque only
- Printed material: PETG at ~30 % infill for link mass estimates

## Consequences

- All of the above lives in [config/robot.yaml](../config/robot.yaml); source code never hardcodes it.
- Changing geometry later means editing the YAML and re-validating torque margins in the twin —
  no source changes.
- CAD (Phase 4) must place joint axes exactly 120 mm apart and the shoulder axis 90 mm above the
  table datum.

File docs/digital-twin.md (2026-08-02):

# Digital Twin (web) — Subsystem Documentation

## Overview

Interactive 3D digital twin of the 3-DOF arm, built so that **the drivetrain is the
independent variable**: per joint, the user picks a drive type (direct 1:1 / planetary /
cycloidal) and a reduction ratio. Efficiency, output backlash, torque cap, and gearbox inertia
are *derived* from the chosen type via characteristic models in the config — the twin exists to
dial in ratios, not to hand-tune gearbox internals. Every displayed quantity — torque margins,
achievable speeds, TCP backlash error, position resolution, move durations, skipped-step risk —
follows from those two choices.
Linkage geometry is fixed (see [linkage-geometry.md](linkage-geometry.md)) and loaded from
[config/robot.yaml](../config/robot.yaml).

Run it:

```
cd web
npm install
npm run dev     # http://localhost:5173
npm test        # core math unit tests (vitest)
```

## Architecture

```
web/src/
  core/          pure math, no rendering, no React — mirrors the future C++ core API
    config.ts        YAML → typed SI-unit RobotConfig
    units.ts         unit conversions, constants
    kinematics.ts    FK, analytical IK (4 branches), Jacobian, workspace boundary
    drivetrain.ts    stepper torque-speed model + gearbox (ratio/efficiency/backlash/cap)
    dynamics.ts      gravity torques, worst-case link inertias
    trajectory.ts    synchronized quintic point-to-point planner
    metrics.ts       aggregation: per-joint budgets, TCP metrics, trajectory audit
  state/         zustand store: independent variables, pose command, motion playback
  three/         React Three Fiber rendering ONLY (no kinematic computation)
  ui/            Tailwind control/metrics panels
```

The layering enforces the project rule that visualization is independent of robot math:
`three/` and `ui/` import from `state/` and `core/`, never the reverse. The C++20 reference
implementation of every `core/` module now lives in [`src/`](cpp-core.md); both test suites
assert the same numeric fixtures, and the remaining Phase 3 step is compiling it with emsdk
and swapping the store's imports to the WASM module.

## Algorithms & equations

**FK** (θ₂ from horizontal, θ₃ relative, world Z-up):
`r = L1·cosθ2 + L2·cos(θ2+θ3)`, `z = h + L1·sinθ2 + L2·sin(θ2+θ3)`,
`tcp = (r·cosθ1, r·sinθ1, z)`.

**IK** — analytical, O(1): law of cosines for θ₃ (`cosθ3 = (d² − L1² − L2²) / 2L1L2`), then
θ₂ by angle subtraction. Four branches are enumerated: {elbow-up, elbow-down} × {front,
base-flipped}. The base-flipped branch (θ₁ + 180°, negative planar radius, arm over the top)
matters because θ₂ spans 0–180°. Unreachable targets, joint-limit violations, straight-arm
singularity (|sin θ₃| small) and base-axis singularity (target on yaw axis) are all reported.

**Jacobian** — analytic 3×3 position Jacobian, validated against central finite differences in
tests. `det J ∝ r·sinθ3` gives the singularity measure.

**Stepper + gearbox model** — motor torque falls linearly from holding torque at standstill to
zero at max speed. At the joint: `τ_avail = min(τ_motor(ω·N)·N·η, τ_cap)`;
`ω_max,joint = ω_max,motor / N`; reflected inertia `= (J_rotor + J_gb)·N²`;
resolution `= step / µstep / N`. Backlash → TCP error via `Σ ‖J_i‖·b_i`.

**Drive-type models** (`core/gearboxModel.ts`, constants in `config/robot.yaml`
`gearbox_models`) — *direct*: ratio locked to 1, near-lossless. *Planetary*: a printed stage
tops out at 6:1; higher ratios stack stages, compounding efficiency (`0.88^stages`) and
accumulating backlash (0.6°/stage) and inertia. *Cycloidal*: 8:1–40:1 in one stage, 75 %
efficient, **negligible backlash by design assumption**, highest printed-torque cap.

**Trajectories** — synchronized quintic time scaling; duration chosen from per-joint velocity
(80 % of drivetrain ceiling) and acceleration (70 % of static torque margin over total inertia)
limits. Every planned move gets a **predictive audit**: 120 dense samples comparing
`|τ_gravity| + I_total·|q̈|` against the speed-derated available torque; a peak over 100 %
means an open-loop stepper would skip steps.

**Collision detection** (`core/collision.ts`, envelopes in `config/robot.yaml` `collision`) —
conservative envelopes: forearm+gripper capsule vs the ground plane, vs flat-topped cylinders
for the base housing and rotating column (a capsule would dome a squat cylinder's top by its
full radius — far too conservative), and vs a shoulder-joint sphere for deep elbow folds (the
forearm capsule is trimmed near its own elbow, where adjacent links legitimately meet). Every
command path is gated: IK drops colliding branches, joint-slider commands are refused, planned
trajectories are sampled densely pose-by-pose before executing (endpoints being safe does not
make the sweep safe), and program rows are validated individually with a per-row reason.

**The move program** (`core/program.ts`, `core/programResolve.ts`, `ui/ProgramPanel.tsx`) — the
sliders *pose* the arm; the program is how you *command* it, and it is the twin's model of how
the physical robot actually works: a queue of moves, each planned, executed to completion, then
held for a dwell before the next starts. Nothing follows the cursor.

Each row is one of three frames, plus a dwell and an enable flag:

| Badge | Frame | Values |
|---|---|---|
| `XYZ` | Cartesian | `x, y, z` mm — solved by IK, elbow branch chained from the previous row |
| `RθZ` | Polar (cylindrical) | `r` mm, `θ` deg, `z` mm — about the base yaw axis |
| `θ` | Joint space | `θ1, θ2, θ3` deg — commanded directly, no IK |

Polar is the arm's own natural frame: FK is literally `tcp = (r·cosθ1, r·sinθ1, z)`, so `r` is
planar reach, `θ` *is* the base angle, and `z` is height. Sweeping the base at fixed radius is
one number here and two coupled ones in Cartesian — a program of `RθZ` rows differing only in
`θ` exports as `MOVEJ` lines with identical shoulder and elbow angles. Negative `r` is legal and
means the same point as `(|r|, θ+180°)`; the IK already models that as the base-flipped branch.
Positional rows (`XYZ`, `RθZ`) share one code path — polar converts to Cartesian, then both go
through the same IK, limit and collision gates.

Rows resolve as you type — reach, joint limits and collision are reported inline per row — so an
unreachable waypoint is something you see and fix, not something silently dropped at load time.

`program.ts` is deliberately kinematics-free (rows, units, text round-trips) so it unit tests in
isolation; `programResolve.ts` is the half that goes through the C++ core.

Running resolves every enabled row up front and commits that snapshot: editing mid-run affects
the *next* run, matching the firmware's contract that a queued move is fixed once accepted. The
runner supports run / pause / resume / single-step / loop. Pause shifts the motion clock rather
than replanning, so a paused leg resumes on the exact profile it was already following. A
swept-path collision that only appears between two individually-safe waypoints stops the run
where it is and names the offending move. The final report aggregates the worst torque
utilization across every leg.

**Program I/O** — CSV rows are `[kind,] a, b, c [, dwell]`; the optional leading `C`/`P`/`J` tag
(or the spelled-out `cartesian`/`polar`/`joints`) lets a mixed program round-trip, and `!` before
it marks a disabled row. Import *appends to the editor* rather than auto-running, so an imported
file can be inspected and corrected first.

Export as CSV (everything, disabled rows included) or as a **robot script** for
`python/run_script.py` — only the enabled rows that resolved, emitted as `MOVEJ` with the joint
angles the twin validated. Positional rows go out as joint angles too, with the authored target
kept as a comment: the twin has already chosen an IK branch and proved that pose safe, so sending
angles guarantees the hardware reproduces what was simulated instead of re-solving IK on the
ESP32 and possibly landing on the other elbow branch. It also lets the runner split each move
joint-by-joint for the shared-rail bench, which it cannot do for `MOVEL` — and there is no polar
verb on the wire at all, so `RθZ` rows could not round-trip any other way.

## Assumptions & limitations

- Rod/point-mass model (no full inertia tensors yet); base-joint inertia uses the extended-arm
  worst case regardless of pose.
- Linear torque-speed curve; real steppers have resonance dips and a nonlinear knee.
- No Coriolis/centrifugal terms; acceptable at these speeds, revisit with dynamics phase.
- Backlash treated as a static worst-case position band, not simulated as hysteresis.
- Drive-type characteristics (per-stage efficiency, backlash, torque caps) are representative
  estimates for printed PETG gearboxes; replace with measured values once prototypes exist.
- Cycloidal backlash is assumed negligible (a property of preloaded cycloidal drives, adopted
  as a design requirement for ours).

## Future improvements

- Replace `core/` with the C++20 library compiled to WASM (identical API).
- Pose-dependent inertia matrix; inverse dynamics along trajectories.
- Draggable 3D target (transform gizmo), joint-space trace, torque-over-time plots.
- Persist gearbox configurations back to YAML for the CAD pipeline (Phase 4).

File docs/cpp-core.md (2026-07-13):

# C++ Core — Subsystem Documentation

## Overview

`src/` is the C++20 implementation of every computational module of the digital twin —
kinematics, drivetrain, gearbox derivation, dynamics, trajectory planning, metrics/audit,
collision detection, and CSV waypoint parsing. It is the **reference implementation** destined
to power all three targets from CLAUDE.md: native simulation, the WebAssembly module behind the
web twin, and (subset) embedded firmware.

Each file mirrors a `web/src/core/*.ts` module one-for-one, and the two test suites assert the
**same numeric fixtures** (gravity 1.166 / 0.294 N·m at full extension, 0.88² two-stage
planetary efficiency, identical IK round-trip grids and collision poses), so any divergence
between the implementations fails a test on one side or the other.

## Building (native)

Requires CMake ≥ 3.20 and a C++20 compiler (developed against MSVC 19.44 / VS 2022):

```
cmake -S . -B build -G "Visual Studio 17 2022" -A x64
cmake --build build --config Release
ctest --test-dir build -C Release        # or run build/Release/robottwin_tests.exe
```

The test binary loads the same `config/robot.yaml` the web twin uses (path injected via the
`ROBOTTWIN_CONFIG_PATH` compile definition).

## Building (WebAssembly)

`src/wasm/bindings.cpp` exposes the full API through embind. With the
[emsdk](https://emscripten.org/docs/getting_started/downloads.html) installed:

```
emcmake cmake -S . -B build-wasm
cmake --build build-wasm       # emits web/src/wasm/robottwin.{js,wasm} (ES6 module)
```

The JS side keeps YAML parsing (it already ships the config text) and passes a plain
`RobotConfig` object across the boundary; `src/config/yaml_lite.*` is native-only.

> Status: **integrated.** emsdk lives at `C:\Users\kgunner\emsdk` (activate with
> `emsdk_env.ps1`; pass `-DCMAKE_MAKE_PROGRAM=<winget ninja path>` on this machine). The web
> app's math calls go through `web/src/core/api.ts`, a thin adapter over the embind module
> (enum↔union-string conversion, joint records↔arrays; results cross as plain JS objects, no
> handles to delete). The TypeScript implementations in `web/src/core/` remain as the parity
> mirror exercised by vitest.

## Layout

| Path | Contents | Mirrors |
|---|---|---|
| `src/math/` | units, Vec3 helpers | `units.ts` |
| `src/config/` | typed config, YAML-subset loader (native only) | `config.ts` |
| `src/kinematics/` | FK, analytical IK (4 branches), Jacobian, workspace | `kinematics.ts` |
| `src/drivetrain/` | stepper curve, gearbox math, type→params derivation | `drivetrain.ts`, `gearboxModel.ts` |
| `src/dynamics/` | gravity torques, worst-case inertias | `dynamics.ts` |
| `src/planning/` | synchronized quintic point-to-point | `trajectory.ts` |
| `src/simulation/` | per-joint metrics, predictive trajectory audit | `metrics.ts` |
| `src/geometry/` | capsule/cylinder collision checks | `collision.ts` |
| `src/io/` | CSV waypoint parsing/validation | `waypoints.ts` |
| `src/wasm/` | embind bindings (Emscripten builds only) | — |
| `tests/` | self-registering micro-harness, 55 tests / ~1800 checks | `web/src/core/*.test.ts` |

## Design decisions

- **No external dependencies.** The YAML loader is a deliberate ~150-line subset parser scoped
  to exactly `robot.yaml`'s shape (2-space-indented maps, scalars, inline numeric lists,
  comments) and rejects everything else loudly. The test harness is ~70 lines. This keeps the
  core compilable offline on Windows, Linux, WASM, and eventually bare-metal.
- **Fixed-capacity results in hot paths** (`IkResult` holds ≤ 4 solutions inline, collision
  issues ≤ 5) — no heap allocation in kinematics/collision/dynamics, for firmware reuse.
  `std::vector`/`std::string` appear only in inherently variable-size I/O (waypoints, workspace
  boundary).
- **Collision issues are enums** with `describe()` for UI strings, so firmware can act on codes
  without string handling.

## Limitations / next steps

- Compile and smoke-test the embind module with emsdk; swap `web/src/state/store.ts` to import
  the WASM API and demote `web/src/core/` to type definitions.
- The YAML-subset parser intentionally fails on block lists and anchors; extend it only if the
  config schema ever needs them.
- CI should build both suites (`npm test` + `ctest`) so the mirrored fixtures actually gate
  divergence.

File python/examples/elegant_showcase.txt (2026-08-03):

# RobotTwin elegant showcase — a choreographed demo that reads as phrases
# rather than a list of moves.
# Run:  python python/run_script.py --port COM3 python/examples/elegant_showcase.txt
# Preview (no hardware):
#   python python/run_script.py --dry-run --start 0,90,-90 python/examples/elegant_showcase.txt
#
# How the elegance is actually achieved -- three rules, all forced by the rig:
#
#   1. ONE JOINT PER MOVE. The runner splits a multi-joint MOVEJ into sequential
#      single-joint moves so the shared motor rail only ever drives one coil, so
#      a two-joint line would execute as two moves with a hitch between them.
#      Every MOVEJ below turns exactly one joint: the script reads the way the
#      arm actually moves.
#
#   2. GESTURES, NOT STEPS. Consecutive MOVEJ lines run back to back -- the
#      runner sends the next the instant EV MOVE_DONE arrives. So moves with no
#      SLEEP between them chain into one continuous gesture, and SLEEP is used
#      only where a pause is meant to be seen. Read the blank lines as breaths.
#
#   3. MODEST MOVES, ON PURPOSE. min_move_duration_s floors a short move at
#      0.25 s, so small moves are unhurried and controlled. Elbow moves are kept
#      to <= 24 deg (the bench proved 10 deg clean and 90 deg stalling), shoulder
#      moves to <= 20 deg. The base is direct-drive with no reduction to slow it,
#      so it is the one axis that can whip -- it gets a single long sweep as the
#      centerpiece and short moves everywhere else.
#
# Posture: the shoulder stays in the 72-104 band (near vertical) and the elbow
# never opens past -66, so the arm's mass stays tucked over the base and the
# straight-arm singularity at elbow 0 is never approached.

PING
ENABLE

# Datum: place the arm at base 0deg, shoulder 90deg (upper arm vertical),
# elbow -90deg before running. Adjust to wherever the arm actually is.
SETHOME 0 90 -90
PAYLOAD 0
TELEM 2

# --- I. Greeting ------------------------------------------------------------
# Lean in and open the forearm as one motion, hold the bow, then straighten.
MOVEJ 0 76 -90
MOVEJ 0 76 -68
SLEEP 1
MOVEJ 0 76 -92
MOVEJ 0 92 -92
SLEEP 1

# --- II. The pan ------------------------------------------------------------
# Gather the forearm in first: tucked mass is a short moment arm, so the long
# sweep costs almost nothing. Then a pendulum -- out, across, back to center.
MOVEJ 0 92 -114
MOVEJ -75 92 -114
SLEEP 1

# The centerpiece: one uninterrupted 150 deg sweep on the gravity-free axis.
MOVEJ 75 92 -114
SLEEP 1
MOVEJ 0 92 -114
SLEEP 1

# --- III. The reach ---------------------------------------------------------
# Drop the shoulder, then unfold the elbow in two chained steps so the forearm
# extends as one slow line instead of one lunge. Hold, then withdraw the same
# way in reverse.
MOVEJ 0 72 -114
MOVEJ 0 72 -90
MOVEJ 0 72 -66
SLEEP 2
MOVEJ 0 72 -90
MOVEJ 0 72 -114
MOVEJ 0 92 -114
SLEEP 1

# --- IV. Diagonals ----------------------------------------------------------
# Alternating base and shoulder traces a diagonal across the workspace; the
# elbow adds a small flourish at the far corner.
MOVEJ 65 92 -114
MOVEJ 65 104 -114
MOVEJ 65 104 -92
SLEEP 1
MOVEJ 65 104 -114
MOVEJ -65 104 -114
MOVEJ -65 84 -114
SLEEP 1

# --- V. Return --------------------------------------------------------------
# Unwind to the datum in the order the arm left it: base, then shoulder, then
# elbow -- the pose it was placed in at the start.
MOVEJ 0 84 -114
MOVEJ 0 90 -114
MOVEJ 0 90 -90
SLEEP 1

TELEM 0
DISABLE

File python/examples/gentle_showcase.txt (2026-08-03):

# RobotTwin gentle showcase — a flowing demo that stays easy on the drivetrain.
# Run:  python python/run_script.py --port COM5 python/examples/gentle_showcase.txt
# Preview (no hardware):
#   python python/run_script.py --dry-run --start 0,90,-90 python/examples/gentle_showcase.txt

PING
ENABLE

# Datum: place the arm at base 0deg, shoulder 90deg (upper arm vertical),
# elbow -90deg before running.
SETHOME 0 90 -90
PAYLOAD 0
TELEM 2

# 1) a small bow hello
MOVEJ 0 80 -105
SLEEP 1
MOVEJ 0 90 -90
SLEEP 1

# 2) rise into a relaxed, folded "ready" pose (arm up, elbow tucked in)
MOVEJ 0 105 -105
SLEEP 1

# 3) slow pan left, full sweep right, back to center -- the dramatic part
MOVEJ -80 105 -105
SLEEP 1
MOVEJ 80 105 -105
SLEEP 1
MOVEJ 0 105 -105
SLEEP 1

# 4) reach forward and draw back (elbow only half-opens, shoulder stays
#    near vertical so the load stays over the base)
MOVEJ 0 100 -55
SLEEP 1
MOVEJ 0 100 -110
SLEEP 1

# 5) two diagonal flourishes across the workspace
MOVEJ 60 95 -75
SLEEP 1
MOVEJ -60 95 -105
SLEEP 1

# 6) settle home and rest the motors
MOVEJ 0 90 -90
SLEEP 1
TELEM 0
DISABLE

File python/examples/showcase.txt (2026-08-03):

# RobotTwin showcase — a four-move joint-space demo off the 0/90/-90 datum.
# Run:  python python/run_script.py --port COM5 python/examples/showcase.txt
# Preview (no hardware):
#   python python/run_script.py --dry-run --start 0,90,-90 python/examples/showcase.txt

PING
ENABLE

# Datum: declare the arm's current parked pose. Place the arm at base 0deg,
# shoulder 90deg (upper arm vertical), elbow -90deg before running.
SETHOME 0 90 -90

# Stream live joint state so the motion is visible in the console.
TELEM 2

# 1) swing the base out to +45
MOVEJ 45 90 -90
SLEEP 1

# 2) drop the shoulder to 45
MOVEJ 45 45 -90
SLEEP 1

# 3) open the elbow out to 0 (arm reaches forward)
MOVEJ 45 45 0
SLEEP 1

# 4) sweep the base across to -45
MOVEJ -45 45 0
SLEEP 1

# 5) bend the arm down
MOVEJ -45 45 90
SLEEP 1

TELEM 0
DISABLE

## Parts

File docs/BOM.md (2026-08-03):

# Bill of Materials

Purchased hardware for the full build: base + two pitch joints + the two
cycloidal gearboxes (one 15:1, one 20:1 — put the 20:1 at the shoulder) +
electronics. Sources of truth: `engineering/README.md` (linkage),
`engineering/gearboxes/README.md` (gearboxes, v3),
`config/firmware.yaml` / `docs/firmware.md` (electronics). Quantities are
for one robot with no spares unless noted.

## Motors and drivers

| Item | Qty | Notes |
|---|---|---|
| NEMA 17 stepper, 17HS4401 (5 mm D-shaft, ~40 mm body) | 3 | base direct drive, shoulder, elbow. The CAD assumes the measured 40 mm body and 23.5 mm usable shaft |
| TMC2209 driver module | 3 | step/dir mode, shared EN; configured over single-wire UART at boot (`tmc_uart.enabled: true` — current and microstepping come from `firmware.yaml`, VREF pots unused) |
| Electrolytic capacitor ≥100 µF, ≥35 V | 3 | one across VM per driver |

**A4988 substitution:** needs one firmware tweak — the step engine's STEP
pulses are tens of ns (fine for the TMC2209's 100 ns minimum, below the
A4988's 1 µs), so `step_engine.cpp` must stretch them first — and set
`tmc_uart.enabled: false` (the A4988 has no UART; straps and pots take
over). Otherwise
the interface matches: the firmware drives step/dir/enable only, EN is
active-low on both, and `robot.yaml motor.microstepping: 16` is exactly
the A4988's maximum
(strap MS1=MS2=MS3 high). Set the current-limit pot (VREF) per your
carrier's formula; without a fan hold it to ~1 A/phase, which is ~60 % of
the 17HS4401's rated current — then derate
`robot.yaml motor.holding_torque_nm` (0.45 → ~0.28) so the twin and the
firmware torque governor plan against the torque you actually have.
DRV8825 is the same story with more current headroom (1/16 also available).

## Bearings, shafts, pins

| Item | Qty | Notes |
|---|---|---|
| 608-2RS bearing (8×22×7) | 2 | one per +Y ear (live shaft: outer race in the ear, inner race on the spinning shaft) |
| 6805-2RS bearing (25×37×7) | 3 | yaw support in the base pan + one per drive ear, riding the gearbox output's Ø25.05 seat |
| 6802-2RS bearing (15×24×5) | 4 | two per gearbox, on the eccentric cam |
| 8 mm hardened steel shaft, **cut to 68 mm** | 2 | see "Shaft preparation" below |
| 8 mm set-screw shaft collar (~Ø18×9) | 2 | outboard axial keeper, one per pitch joint |
| Ø6 × 25 mm steel dowel pin | 49 (buy ~55) | 20:1 gearbox: 21 ring + 6 output; 15:1: 16 ring + 6 output |

### Shaft preparation (per shaft, ×2)

- **Cut to 68 mm; no flats** — shafts cut for the dead-axle rev are
  reused unmodified. Since the live-shaft rev (v5) the shaft **is the
  torque path**: it spins with the arm, clamped at both ends by split
  pinches (gearbox output extension on −Y, arm hub on +Y side of the
  span). **Degrease before assembly** — both couplings are friction
  clamps on polished rod; a drop of Loctite 638 in each bore is cheap
  insurance against creep-slip.
- Length derivation (functional 68.0): collar 9 outboard of the +Y ear
  face (25.75) + drive-ear outer face at 35.5 − 2.25 (tip stops shy of
  the gearbox lid face, ~19.5 mm deep in the output's bore). If the
  linkage or casing changes, re-read `shaft_len` from
  `linkage_geometry.py`'s dry-run output.

## Fasteners

M3 socket head throughout. An M3 assortment box (6–40 mm) plus the specific
×40 count covers everything with spares.

| Item | Qty | Where |
|---|---|---|
| M3 × 5.7 heat-set insert (for Ø4.6 pockets) | 26 (+ spares) | coupling top ×4, ear discs 2×6, forearm plate ×4, gripper lid ×6 |
| M3 × 40 | 12 | gearbox through-bolts, 6 per gearbox |
| M3 × 8 | 16 | gearbox cup → motor (2×4), base pan → motor (4), optional hub → sleeve axial locks (2, self-tap into the flat's Ø2.5 pilot), spares |
| M3 × 10 | 4 | column plate → coupling |
| gripper screws (M3 × 8 ×10) | — | per the table in `engineering/gripper/README.md` |
| M3 × 20 + nut | 5 | base shaft-coupling cross-bolt (1) + arm-hub pinch bolts (2 per hub) |
| M3 × 16 + nut | 2 | gearbox-output pinch bolts, one per output |
| M3, length to suit the bench | 4 | pan table mount (Ø120 BCD) |

## Electronics

| Item | Qty | Notes |
|---|---|---|
| ESP32 DevKit (WROOM-32) | 1 | pins per `config/firmware.yaml` |
| Limit switch (lever microswitch) | 3 | **optional** — only for switch-seek `HOME`; this build datums with `SETHOME` (manual pose). Active-low to GND, internal pull-ups |
| Motor PSU, 12–24 V | 1 | ≥5 A at 12 V for three motors; 24 V preferred for speed headroom |
| 1 kΩ resistor | 1 | TMC2209 UART bus: ESP32 GPIO26 (TX) → shared PDN_UART line |
| Hookup wire, dupont/JST, USB cable | — | UART0 console at 115200 |

## Gripper (designed — see `engineering/gripper/`)

Parallel-jaw gripper, designed and audited in
[engineering/gripper/README.md](../engineering/gripper/README.md). The v2
design replaced the NEMA 8 + lead-screw drive: a single **SG-90 micro
servo** turns a printed **lantern pinion** (eight Ø4.5 pins on a Ø18
pitch circle) meshing two **hobbed racks** integrated into the jaw
sliders — jaw opening 0–36 mm over ~115° of servo swing, ~6.5 N per jaw
working, ~56 g, fingertips 71 mm past the TCP plane. Not self-locking:
the servo stays powered while gripping.

The forearm-tip plate provides the mount: outer face = TCP plane, Ø10.5
bore (registers the gripper's pilot boss, passes wiring via the bottom
notch), **4 × M3 heat-set inserts on a Ø16 BCD opening on the OUTER
face** (this rev relocated them — the old inner-face pockets and nut
recess sat unreachable under the beam). The twin's matching yaml:
`masses.gripper_g: 60` and `collision.gripper_extent_mm: 75`; if the
gripper changes, update those and re-check the torque budget
(`python python/validate_cycloid.py` reports the shoulder margins).

Gripper shopping list (details in its README):

| Item | Qty | Notes |
|---|---|---|
| SG-90 9 g micro servo | 1 | drives the lantern pinion directly; clones fine |
| TPU filament (pads) | — | printed jaw faces |
| Arduino Uno | 1 | the gripper node — drives the servo, runs `arduino/gripper_node/` |
| 10 kΩ potentiometer | 1 | manual opening knob on A0; any linear taper |
| 470–1000 µF electrolytic | 1 | across servo V+/GND **at the connector** — covers the stall inrush |
| 0.1 µF ceramic | 1 | in parallel with the above |
| 1 kΩ resistor | 1 | in series on the ESP32 GPIO 13 → Uno D2 relay line |

No lead screw, nut, thrust bearings, homing switch, or extra stepper
driver — the servo replaces all of it.

**The servo does not run on the ESP32.** It hangs off the Uno above, powered
from a bench supply at **5.0 V with a 1 A limit**, deliberately independent of
both the motor supply and the logic rail — a stalled SG-90 pulls ~650 mA, which
is exactly the transient that browns out the board generating step pulses. Only
grounds are shared. GPIO 13 still belongs to the gripper, but it now carries
serial commands to the Uno rather than PWM to the servo. See
[wiring-and-bringup.md](wiring-and-bringup.md) "Gripper node"; the old step/dir
13/14 + limit 27 reservation is obsolete.

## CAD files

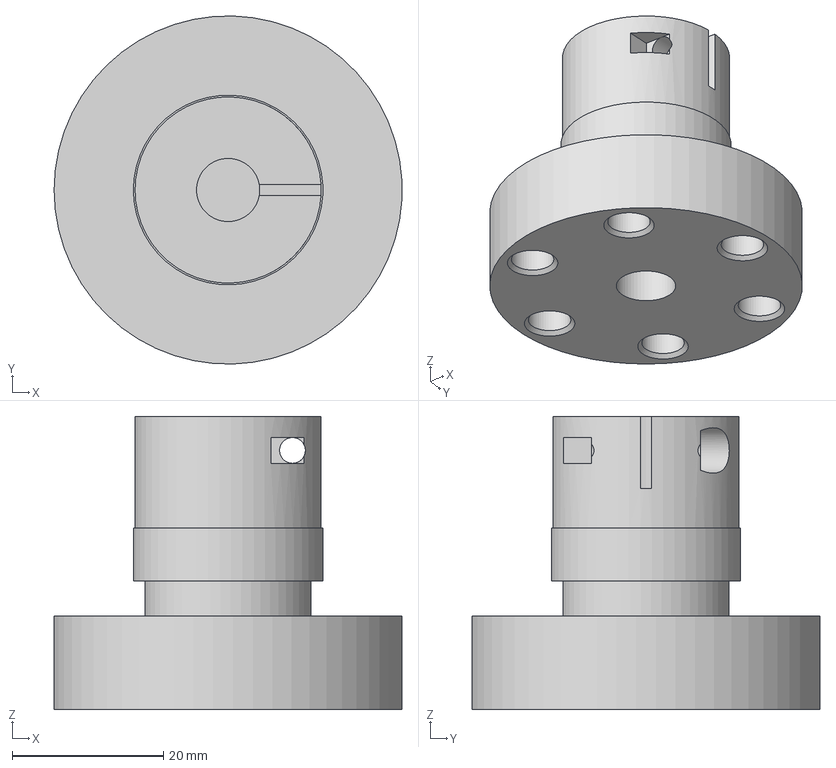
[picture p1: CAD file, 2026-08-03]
engineering/gearboxes/15_1/rt_cyc15_output.step
46.0 x 46.0 x 38.8 mm

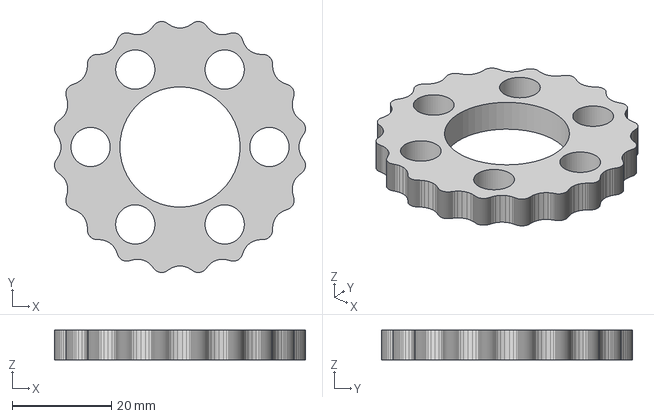
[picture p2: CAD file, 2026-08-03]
engineering/gearboxes/20_1/rt_cyc20_disc.step
50.5 x 50.5 x 6.00 mm

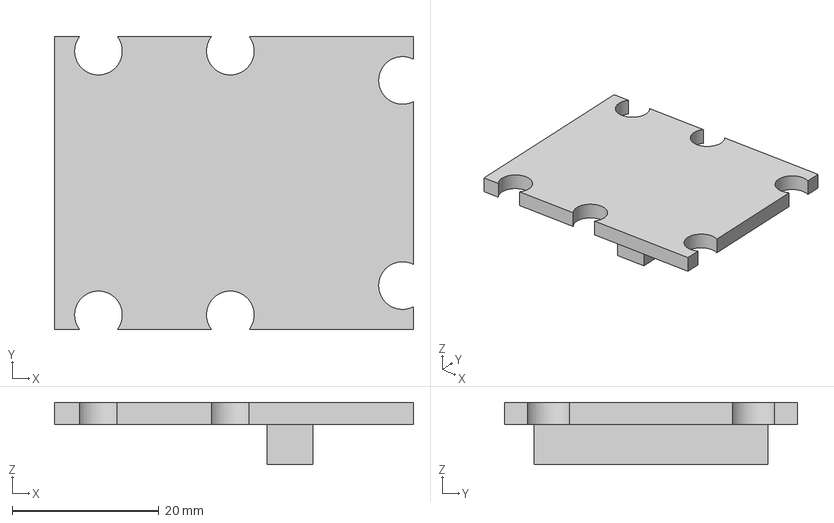
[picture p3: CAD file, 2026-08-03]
engineering/gripper/rt_grip_lid.step
49.0 x 40.0 x 8.50 mm

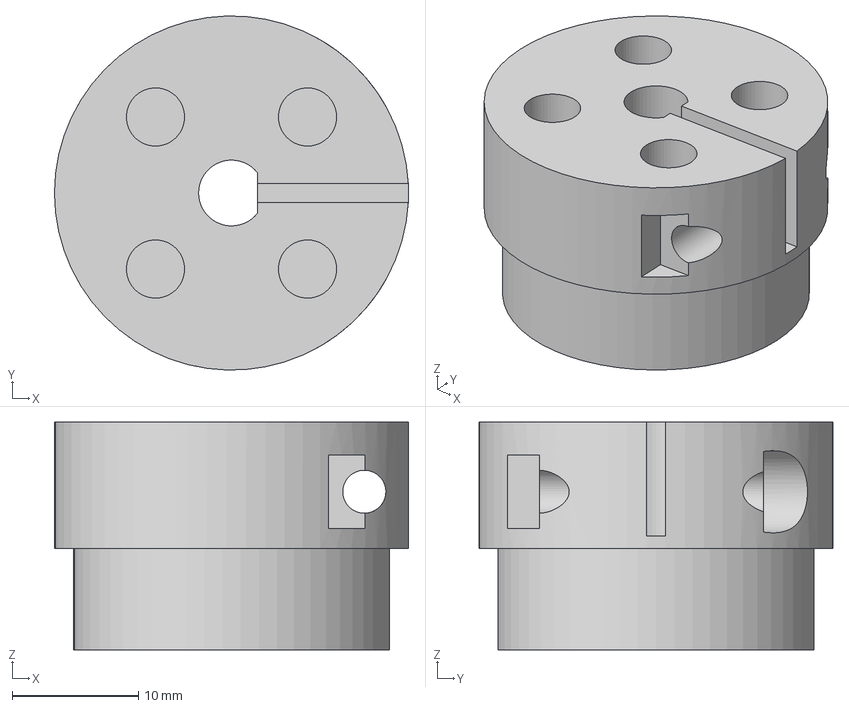
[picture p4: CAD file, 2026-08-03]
engineering/step/rt_shaft_coupling.step
28.0 x 28.0 x 18.0 mm

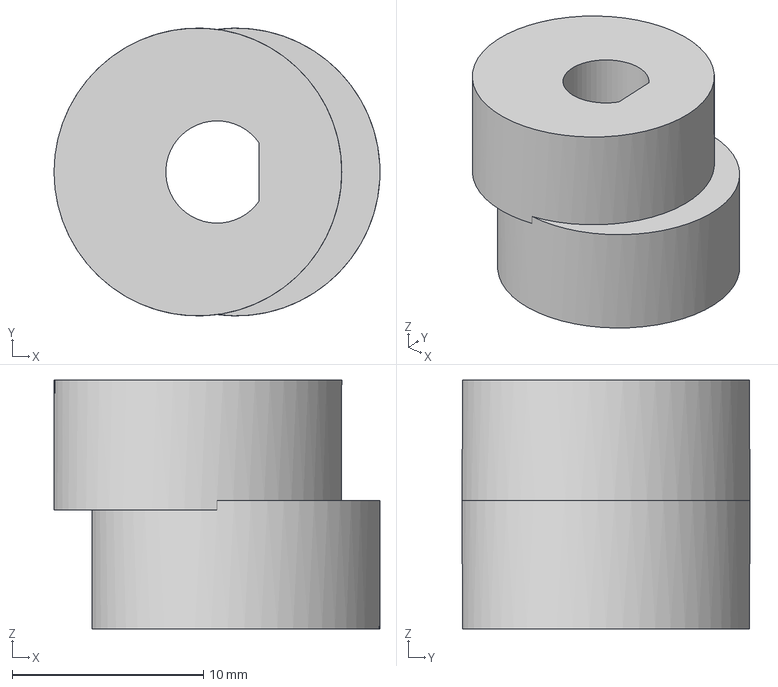
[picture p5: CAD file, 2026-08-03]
engineering/gearboxes/15_1/rt_cyc15_cam.step
17.1 x 15.0 x 13.0 mm

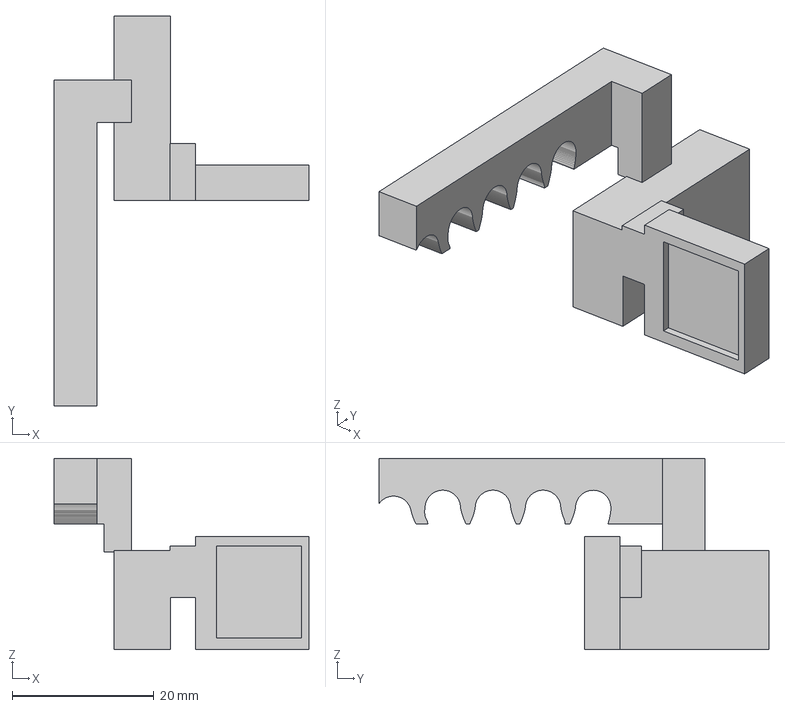
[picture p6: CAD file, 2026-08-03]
engineering/gripper/rt_grip_jaw_p.step
35.9 x 55.0 x 27.0 mm

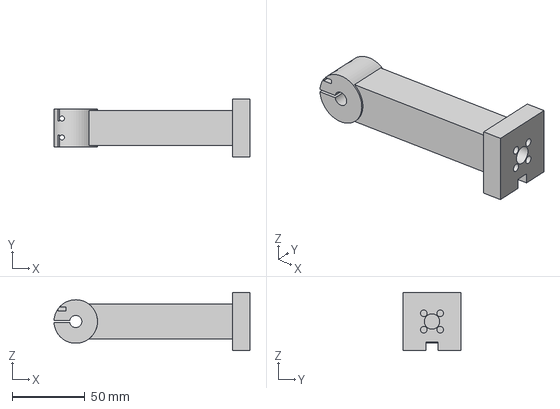
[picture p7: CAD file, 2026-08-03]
engineering/step/rt_forearm.step
135.0 x 40.0 x 40.0 mm

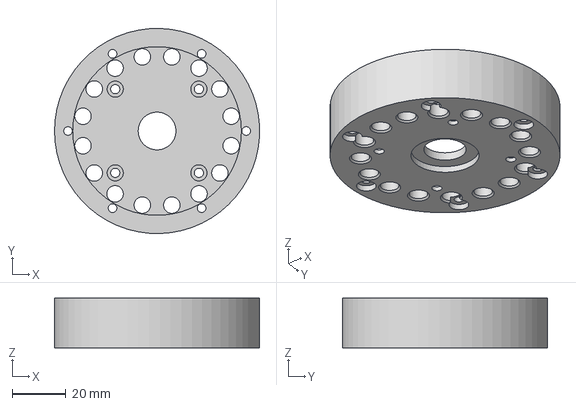
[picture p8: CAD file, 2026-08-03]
engineering/gearboxes/15_1/rt_cyc15_cup.step
75.9 x 76.0 x 18.5 mm

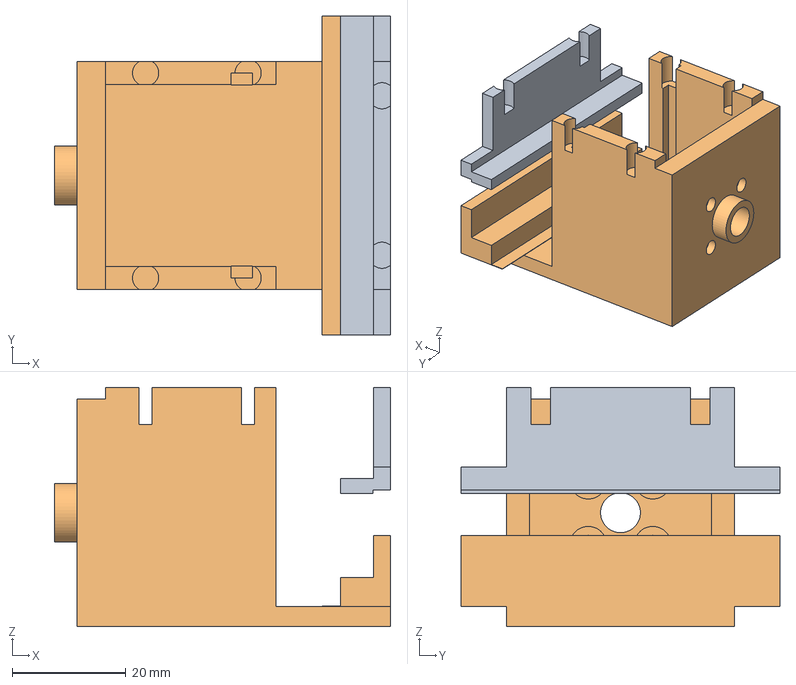
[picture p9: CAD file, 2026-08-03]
engineering/gripper/rt_grip_body.step
59.0 x 56.0 x 42.0 mm

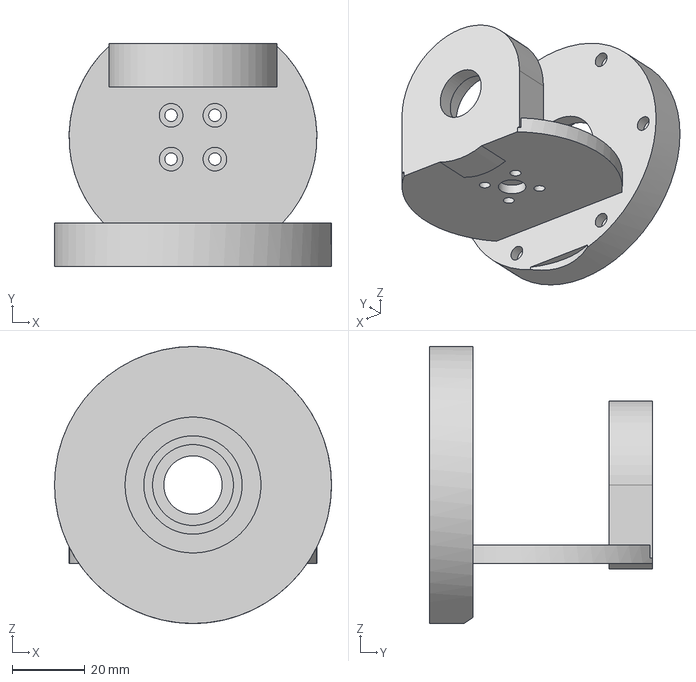
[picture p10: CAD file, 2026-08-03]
engineering/step/rt_yaw_column.step
76.0 x 61.2 x 76.0 mm

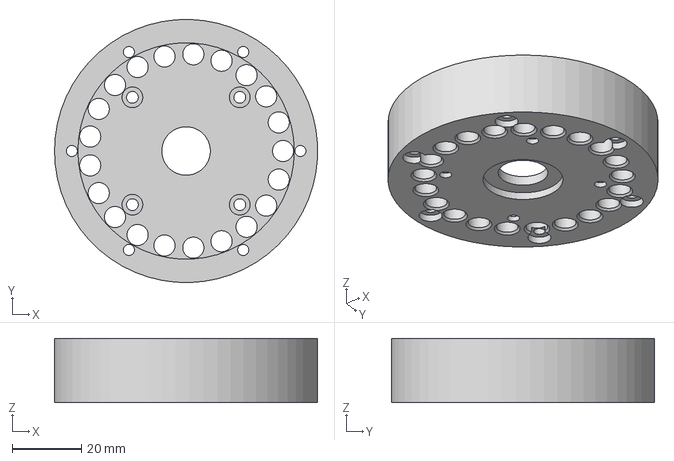
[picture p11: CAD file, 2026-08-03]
engineering/gearboxes/20_1/rt_cyc20_cup.step
75.9 x 76.0 x 18.5 mm

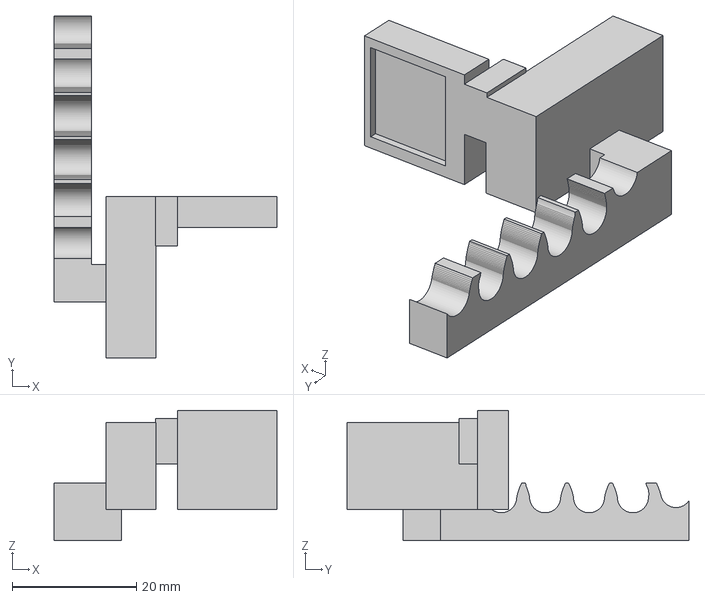
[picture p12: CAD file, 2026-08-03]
engineering/gripper/rt_grip_jaw_n.step
35.9 x 55.0 x 21.0 mm

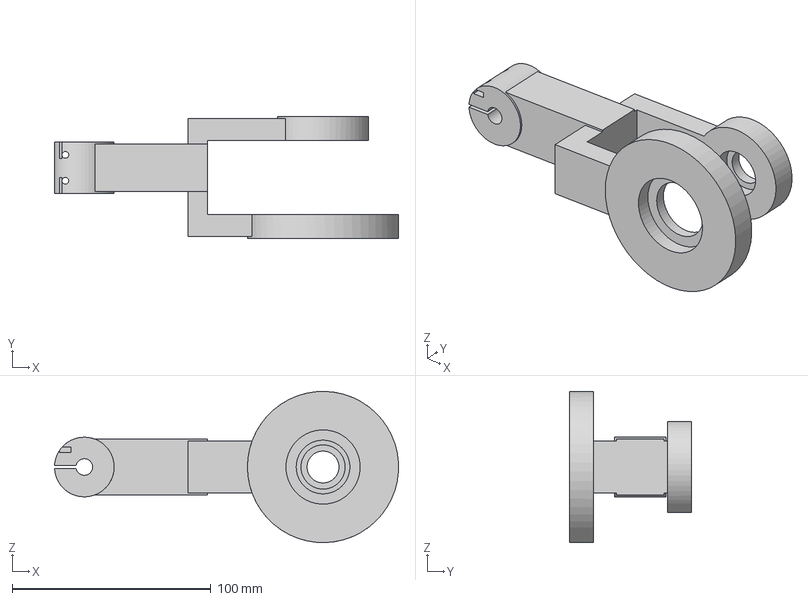
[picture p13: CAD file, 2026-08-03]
engineering/step/rt_upper_arm.step
172.9 x 61.2 x 76.0 mm

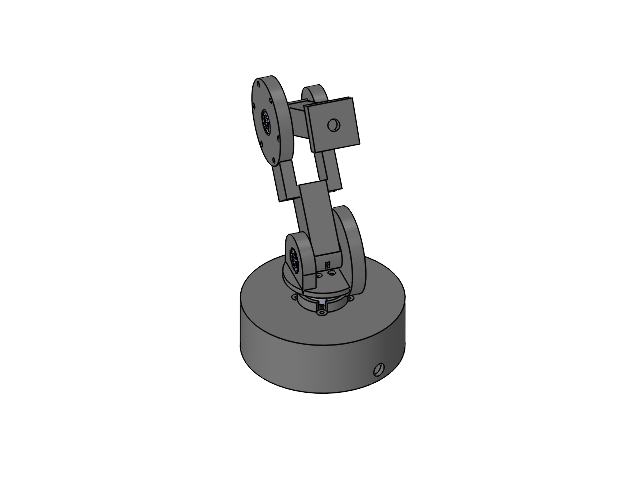
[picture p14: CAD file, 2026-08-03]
engineering/Robot_Assembly.SLDASM
rt_base_pan.step
rt_shaft_coupling.step
Bottom.step
Sheet_metal.step
Top_body.step
Axis.step
625ZZ_001.step x 2
Sticker.step
C-440054-6.step
PCB.step
Conn_cover.step
M3x16-Vis.step x 4
rt_upper_arm.step
608-2rs.step x 4
6805-2rs.step
rt_forearm.step
rt_yaw_column.step

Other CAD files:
engineering/gearboxes/20_1/rt_cyc20_output.step
engineering/gearboxes/20_1/rt_cyc20_cam.step
engineering/gearboxes/15_1/rt_cyc15_disc.step
engineering/gearboxes/15_1/rt_cyc15_lid.step
engineering/f3d/rt-arm-3dof_linkages.f3d
engineering/f3d/rt-gearboxes_cycloidal.f3d
engineering/f3d/rt-gripper.f3d
engineering/f3d/rt_base_pan.f3d
engineering/f3d/rt_forearm.f3d
engineering/f3d/rt_shaft_coupling.f3d
engineering/f3d/rt_upper_arm.f3d
engineering/f3d/rt_yaw_column.f3d
engineering/gearboxes/15_1/rt_cyc15_cam.stl
engineering/gearboxes/15_1/rt_cyc15_cup.stl
engineering/gearboxes/15_1/rt_cyc15_disc.3mf
engineering/gearboxes/15_1/rt_cyc15_disc.stl
engineering/gearboxes/15_1/rt_cyc15_lid.stl
engineering/gearboxes/15_1/rt_cyc15_output.stl
engineering/gearboxes/20_1/rt_cyc20_cam.stl
engineering/gearboxes/20_1/rt_cyc20_cup.stl
engineering/gearboxes/20_1/rt_cyc20_disc.3mf
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

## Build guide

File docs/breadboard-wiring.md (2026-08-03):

# Breadboard Wiring Guide (bench bring-up rig)

How to build the ESP32 + three TMC2209 bench rig on **any** solderless
breadboards — any count, any size, any brand of driver carrier or DevKit.
The guide is written as a net list plus per-module rules, so nothing here
depends on which boards you own or where a module happens to sit. Signals
and pin numbers come from [`config/firmware.yaml`](../config/firmware.yaml)
(UART mode enabled: MS1/MS2 are address straps, current is programmed at
boot). The bring-up *procedure* stays in
[wiring-and-bringup.md](wiring-and-bringup.md). For the specific
dovetailed two-board bench with hole-by-hole instructions, see
[breadboard-step-by-step.md](breadboard-step-by-step.md).

## Read this first — current limits

A breadboard spring contact and its power rails are good for roughly 1 A.
Motor phase current flows through the driver's VM/GND pins, the coil pins,
and the rails, so **this rig is for bench bring-up only**: keep phase
current **≤ 0.8 A** (drop `irun` in `firmware.yaml` to 12–13 and reflash —
current is programmed over UART at boot; the VREF pots do nothing), don't
hang the assembled arm on it, and move to soldered or screw-terminal
wiring for real running. Use 22 AWG solid-core jumpers for anything
carrying motor current, and keep them short.

## What any layout must satisfy

Wire the net list below and respect these four rules, and the rig works
regardless of how you arrange it:

1. **Every module sits across a center divider.** Its left-bank pins land
   in one half (`a–e`), its right-bank pins in the other (`f–j`), so the
   module can never short across its own body.
2. **One rail pair carries one power domain.** 3V3/logic-GND and
   VM/PSU− never share a rail pair. If a board hosts both domains, give
   each its own side.
3. **Each motor's phase current gets its own rail pair back to the
   PSU.** Don't route two motors' VM/GND through the same rails — that's
   the main reason not to crowd drivers onto one board.
4. **Silkscreen always outranks any table here.** DevKit clones shuffle
   pin order and driver brands differ — especially VM/GND, where a
   reversal kills the driver. Wire to labels, not positions.

Positions in this guide are **pin-relative** ("the free hole beside D26")
or net-based; absolute row numbers depend on where you seat a module and
don't matter.

## Buying boards — what matters

Requirements, not a shopping list — buy whatever meets them:

- **Rows per module**: a TMC2209 carrier needs ~10 rows across the
  divider; an ESP32 DevKit ~20. Any half-size board (400 tie-points,
  ~30 rows) fits either; full-size (830) just adds elbow room.
- **Board count**: follows from rule 3 above. One board per driver plus
  one for the ESP32 is the comfortable arrangement; drivers can share a
  board only if each still gets a dedicated rail pair for motor power
  (some boards have two rail pairs per side — meter to confirm they're
  separate).
- **Rails**: you want at least one power + one ground rail per side.
  Check whether the rails run **unbroken** end to end — on many boards
  the painted stripe has a gap mid-length and the rail is electrically
  split there. Meter it; bridge the gap with a jumper if split.
- **ESP32 width**: check your DevKit against the board before committing.
  Narrow modules straddle the divider and leave a free hole column per
  side — all this build needs. Wider ones (38-pin DevKits, typically)
  often leave **zero** free holes on one side; span those across **two
  breadboards placed side by side** (inner rails removed from play) for
  full hole access on both sides. One extra cheap board beats fighting a
  too-wide module.
- Solid-core jumper kit (22 AWG) and a few Dupont leads for the motors.

## Rail conventions used below

- **Logic rails**: red = 3V3, blue = logic GND. The ESP32's board uses
  these on both sides (bridge its two blue rails together).
- **Motor rails**: red = VM (PSU +), blue = PSU −. Each driver gets its
  own motor rail pair on the side nearest its VM/GND pins.
- On a board hosting one driver, that naturally becomes: logic rails on
  the driver's logic side, motor rails on its power side. Motor power
  never touches a logic rail.

## The net list (the actual source of truth)

Every connection in the rig. If you wire exactly this, on any boards, it
works:

| # | From | To |
|---|---|---|
| 1 | ESP32 3V3 | 3V3 rail → each driver's VIO, MS straps per table below |
| 2 | ESP32 GND | logic-GND rail → each driver's logic-GND pin, PSU − (one reference jumper) |
| 3 | ESP32 D23 | EN on **all three** drivers (daisy-chain) |
| 4 | ESP32 D4 / D27 | base driver STEP / DIR |
| 5 | ESP32 D18 / D19 | shoulder driver STEP / DIR |
| 6 | ESP32 D21 / D22 | elbow driver STEP / DIR |
| 7 | ESP32 D26 → **1 kΩ resistor** | PDN_UART on all three drivers, bussed |
| 8 | PSU + / PSU − | each driver's VM / GND (motor side), with a **100 µF cap** (+ to VM) at each driver |
| 9 | Motor coils | one coil pair to the driver's A outputs, the other to its B outputs (labels vary by brand — 1A/1B/2A/2B on most carriers) |

This arm has **no limit switches** (none designed in, no hard stops to mount
them against); the datum is set in firmware with `SETHOME`, so nothing wires
to a switch input. Leave empty: ESP32 VIN (USB powers the board — **never**
the motor PSU), D13 (reserved for the relay link to the gripper node's
Arduino — the servo runs off that board, not this one), GPIO32/33/25
(free — no switches), driver CLK pins if present.

## ESP32 module

1. Seat the module across the divider, USB connector overhanging the
   board edge so the cable fits.
2. Find 3V3 and GND on the silkscreen. 3V3 → red rail; GND → blue rail;
   bridge the two blue rails at the far end.
3. UART resistor: 1 kΩ from the free hole beside D26 to any empty row;
   from that row, one jumper leaves for the driver PDN bus (net 7).
4. Signal jumpers for nets 3–6 leave from the free holes beside D23,
   D4, D27 (base), D18/D19 (shoulder), D21/D22 (elbow).

## Driver modules (three TMC2209s)

Seat each module across a divider. Locate these pin groups on **your**
carrier's silkscreen before wiring anything: VM + motor GND, VIO + logic
GND, the four coil outputs, STEP/DIR, EN, MS1/MS2, PDN_UART. (For
orientation only: StepStick-format carriers put motor power and coils on
one bank, logic and control on the other, but pin order differs between
brands — trust the labels, not a remembered layout.)

Per driver:

1. **Cap first**: 100 µF electrolytic into the motor rails — **+ leg in
   red (VM), − leg in blue.** Check the stripe; backwards electrolytics
   vent.
2. VM → motor red rail; the motor GND beside it → motor blue rail. PSU
   + / − → those rails (use a DC-jack breakout or ferrules — no bare
   stranded wire in spring contacts).
3. VIO → logic red rail; the logic-GND pin (the one at the VIO end, not
   the one beside VM) → logic blue rail.
4. **Address straps** (logic red rail = high, logic blue rail = low) —
   the one step that differs per driver, and every driver must be unique:

   | Joint | Address | MS1 | MS2 |
   |---|---|---|---|
   | base | 0 | low | low |
   | shoulder | 1 | **high** | low |
   | elbow | 2 | low | **high** |

5. PDN_UART joins the bus from the ESP32's 1 kΩ resistor; daisy-chain it
   onward from a free hole in the same row. If your carrier breaks the pin
   out twice, check the labels: two pads both marked PDN are the same net —
   use either; pads split into **TX and RX** are two legs of the interface —
   the bus wire goes to **RX** (this build's UART is write-only) and TX
   stays empty. CLK, if present, stays empty.
6. EN joins the D23 daisy-chain the same way: jumper in from the previous
   driver, jumper out to the next.
7. STEP and DIR: jumpers from the matching ESP32 pins (nets 4–6).
8. Motor: find the coil pairs with a meter (a pair reads a few ohms;
   across coils is open), one pair into the A outputs, the other into
   the B outputs — directly into the free holes beside those pins. A
   wrong pairing guess just reverses direction; `invert_dir` in
   `firmware.yaml` fixes it later.
9. Current: nothing to set on the module — the firmware programs
   `irun`/`ihold` at boot and the VREF pot is ignored. Respect the
   breadboard ceiling from the warning at the top.

## Grounding, in one paragraph

All grounds end up common, deliberately: each driver's motor-GND returns
to the PSU on its own motor rail pair; each driver's logic-GND pin ties
to the logic blue rail, which daisy-chains back to the ESP32's blue rail;
and one reference jumper ties PSU − to the ESP32 blue rail so the logic
reference doesn't depend on paths through the drivers. Keep motor-current
wiring (motor rails) short and fat, and don't route motor return through
the logic daisy-chain.

## Power-up order

1. Everything wired, PSU **off**, USB unplugged. Re-check every VM/GND
   landing against the silkscreen, cap polarity, and that the three
   address straps are all different.
2. USB in, PSU still off → stage-1 smoke test (`PING`) from
   [wiring-and-bringup.md](wiring-and-bringup.md).
3. PSU on, motors loose on the bench → `ENABLE`, feel for holding torque,
   then set the datum with `SETHOME` (this arm has no switches).
4. Anything hot to the touch within seconds → power off and find the
   miswire before it finds the driver.

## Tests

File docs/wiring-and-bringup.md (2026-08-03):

# Wiring & Bring-Up Guide

How to wire the ESP32 controller to the three joint motors and get the arm
moving for the first time. Companion to [firmware.md](firmware.md) (what the
firmware does) and [BOM.md](BOM.md) (what to buy). The single source of truth
for every pin below is [`config/firmware.yaml`](../config/firmware.yaml) —
if this document and that file ever disagree, the YAML wins, because it is
what actually gets flashed.

## What you need

From the [BOM](BOM.md) electronics section:

- ESP32 DevKit (WROOM-32, the common 30/38-pin board)
- 3 × TMC2209 stepper driver modules (StepStick/BTT-style carriers)
- 3 × NEMA 17 steppers (17HS4401 or similar, 4-wire bipolar)
- 3 × electrolytic capacitors, ≥100 µF ≥35 V (one across VM per driver)
- Motor PSU: 12–24 V DC, ≥5 A at 12 V (24 V preferred for speed headroom)
- USB cable (powers the ESP32 and carries the serial console)
- Hookup wire; 1 × 1 kΩ resistor for the TMC2209 UART bus (TX → PDN_UART)
- 1 × SG-90 hobby servo (the gripper's actuator) on 5 V

A breadboard works for the smoke test, but solder or use crimped dupont/JST
connections for anything that moves — a step pin that loses contact mid-move
means lost steps the firmware cannot detect. For a bench rig, there is a
board-agnostic breadboard layout (net list + per-module rules, works on
any boards) in [breadboard-wiring.md](breadboard-wiring.md) (drop `irun`
so phase current stays ≤ 0.8 A on breadboards), and a hole-by-hole
step-by-step build for the dovetailed two-board bench in
[breadboard-step-by-step.md](breadboard-step-by-step.md).

## Power architecture

Three independent supplies with a **common ground**:

- **Logic**: the ESP32 is powered over USB. Each TMC2209's VIO pin takes
  3.3 V from the ESP32's 3V3 pin.
- **Motor power**: the 12–24 V PSU feeds each driver's VM/GND. Put one
  ≥100 µF electrolytic directly across VM/GND at each driver — TMC2209s die
  from inductive voltage spikes without it.
- **Gripper**: a bench supply at **5.0 V with a 1 A current limit** feeds the
  servo, and the Arduino driving it runs off host USB. Nothing here is derived
  from the motor supply — see "Gripper node".
- **Tie PSU ground to ESP32 GND**, and the servo supply's − to both. Without
  the shared reference the step/dir signals float, the drivers behave
  erratically, and the relay link to the Arduino cannot be read at all.

Only grounds are shared. No two of the three rails meet anywhere else.

Rules that prevent dead drivers:

- **Never connect or disconnect a motor while VM is powered.** This is the
  classic way to kill a TMC2209.
- Power-up order doesn't otherwise matter (the shared EN line boots
  disabled), but wire the caps before first applying VM.

## Pin map

All values from `config/firmware.yaml`. Step/dir/enable must stay below
GPIO32 (the step ISR writes the low GPIO bank's registers).

This arm has **no limit switches** — it has none designed in, and no hard
stops to mount them against — so nothing is wired to a switch input and the
datum is set manually with `SETHOME` (see the bring-up procedure). GPIO32/33/25
are consequently free.

> The base joint uses GPIO4/GPIO27 rather than the GPIO16/GPIO17 you'll see
> on many WROOM-32 pinout diagrams: some 30-pin DevKit revisions don't break
> those two out (the ELEGOO DevKit V1 TypeC does, labeled RX2/TX2 — the
> config keeps 4/27 so either works). GPIO4/27 are the free, non-strapping,
> sub-GPIO32 pins that satisfy the same constraints; GPIO14 is the remaining
> spare. If your board *does* expose 16/17 and you'd rather use them, change
> `joints.base.step_pin`/`dir_pin` in `firmware.yaml` and reflash.

| Signal | ESP32 GPIO | Goes to |
| --- | --- | --- |
| Base STEP | 4 | base driver STEP |
| Base DIR | 27 | base driver DIR |
| Shoulder STEP | 18 | shoulder driver STEP |
| Shoulder DIR | 19 | shoulder driver DIR |
| Elbow STEP | 21 | elbow driver STEP |
| Elbow DIR | 22 | elbow driver DIR |
| Driver ENABLE (shared) | 23 | EN on**all three** drivers (active-low) |
| TMC UART TX | 26 | 1 kΩ → shared PDN_UART line, all three drivers |
| Gripper relay TX | 13 | 1 kΩ → Arduino Uno D2 (gripper node) |

**The servo does not connect to the ESP32.** It hangs off an Arduino Uno with
its own supply, and GPIO 13 — which used to carry the servo's PWM directly —
now carries commands to that Uno instead. The reasons are the ones this document
used to list as warnings: a stalled SG-90 draws ~650 mA, which is exactly the
transient that browns out the board generating step pulses, and an SG-90 wants
5 V logic rather than the ESP32's 3.3 V. See "Gripper node" below.
GPIO32/33/25 are unused (no limit switches).

```
                 ESP32 DevKit (WROOM-32)
                ┌───────────────────────┐
   USB ────────►│ 5V/USB          3V3   ├──► VIO on all 3 drivers
                │                 GND   ├──► common ground (PSU − too)
                │ GPIO4  ─ STEP ┐       │
                │ GPIO27 ─ DIR  ├─ base driver
                │ GPIO18 ─ STEP ┐       │
                │ GPIO19 ─ DIR  ├─ shoulder driver
                │ GPIO21 ─ STEP ┐       │
                │ GPIO22 ─ DIR  ├─ elbow driver
                │ GPIO23 ─ EN ──┴─┴─┴─ EN on all three (active-low)
                │ GPIO26 ─ 1kΩ ─ PDN_UART bus (all three)
                │ GPIO13 ─ 1kΩ ─ Uno D2 (gripper node, one-way)
                └───────────────────────┘

     12–24 V PSU ──┬── VM/GND driver 1 (+100 µF cap at the driver)
                   ├── VM/GND driver 2 (+100 µF)
                   └── VM/GND driver 3 (+100 µF)
```

## Gripper node (Arduino Uno)

The SG-90 lives on its own board. The ESP32 sends it commands over a single
wire and never hears back.

| Uno pin | Connect to |
| --- | --- |
| D9 | SG-90 signal wire (orange) |
| A0 | Potentiometer wiper; the pot's two ends go to Uno 5 V and GND |
| D2 | ESP32 GPIO 13 through 1 kΩ — the relay link |
| D3 | Nothing. Reserved for a return path |
| GND | Servo brown wire, servo supply −, **and** ESP32 GND |
| USB | Host PC — power, sketch uploads, and the node's own console |

Servo power comes from a bench supply set to **5.0 V with a 1 A limit**, wired
straight to the servo's red and brown wires. Fit a **470–1000 µF electrolytic
plus a 0.1 µF ceramic across V+/GND at the servo connector**: a bench supply's
regulation loop responds in milliseconds and the servo's inrush is faster than
that, so the capacitor — not the supply — is what actually covers the
transient.

```
        Arduino Uno                      bench PSU 5.0 V / 1 A limit
       ┌─────────────┐                        │        │
 USB ──┤ D9  ────────┼── SG-90 signal (orange)│        │
       │ A0  ────────┼── knob wiper           │        │
       │ D2  ◄─ 1kΩ ─┼── ESP32 GPIO13         ├── red ─┴─ SG-90 V+
       │ D13 (LED)   │                        │       (+470–1000 µF here)
       │ GND ────────┼────────────────────────┴── brown ── SG-90 GND
       └─────────────┘         └── star ground: also ESP32 GND, PSU −
```

Three things that will bite you:

- **Never feed 5 V into the Uno's barrel jack.** That input runs through the
  onboard AMS1117 regulator, which needs ~6.5 V; 5 V there leaves the board's
  5 V rail near 3.9 V and erratic. A 5 V source goes into the USB connector.
- **Never jumper the servo supply onto the Uno's 5V pin.** The rails stay
  separate; only the grounds meet.
- **The relay must not land on D0 or D1.** Those are the Uno's hardware UART,
  wired to its USB chip — using them would fight the console and break sketch
  uploads. That is why D2 is a `SoftwareSerial` receive pin.

The 3.3 V the ESP32 drives into D2 is above the Uno's 3.0 V logic-high
threshold, so it reads correctly, but only by 0.3 V. If bring-up shows garbled
bytes, drop `relay_baud` to 9600 before reaching for a level shifter.

Build and flash it from `arduino/gripper_node/` — see the README there.

## Per-driver wiring (TMC2209 carrier)

Each of the three drivers gets:

| Driver pin | Connect to |
| --- | --- |
| VM / GND (motor side)  | PSU + / PSU − , with the 100 µF cap across them |
| VIO / GND (logic side) | ESP32 3V3 / GND |
| STEP, DIR | the joint's GPIOs from the pin map |
| EN | GPIO23 (shared by all three) |
| A1, A2, B1, B2 | one motor coil per pair (see below) |
| MS1, MS2 | UART address straps — per the table below |
| PDN_UART | shared bus from GPIO26 (through the 1 kΩ) |

**Motor coils:** a 4-wire bipolar stepper has two coils. Find the pairs with
a multimeter (a coil pair shows a few ohms; across coils is open). One pair
goes to A1/A2, the other to B1/B2. Which pair is "A" and which wire is which
within a pair only affects rotation direction — fixed later in software with
`invert_dir`, so don't agonize over it.

**Current limit (set over UART, not the pot):** this build runs
`tmc_uart.enabled: true`, so at boot the firmware programs each driver's
run/hold current from `firmware.yaml` (`irun: 16`, `ihold: 8`, on a 0–31
scale) and the onboard VREF potentiometer is **ignored** — don't chase it
with a screwdriver. With the 110 mΩ sense resistors on typical carriers,
`irun: 16` lands near **0.9–1.0 A RMS**, right for an uncooled 17HS4401
(rated 1.7 A); sense values differ between brands, so if a motor runs
notably weak or hot, check your carrier's sense resistors before blaming
the config. Changing current = edit `irun`/`ihold` and reflash (the YAML
is embedded in the image). If you settle well below rated current, derate
`robot.yaml motor.holding_torque_nm` proportionally so the twin and the
firmware torque governor plan against the torque you actually have.

## UART address straps (MS1/MS2) and the PDN bus

With the UART enabled, MS1/MS2 are **address pins**, not microstep
selects — the firmware pushes the microstep resolution (1/16, from
`robot.yaml motor.microstepping`) over the wire at boot via CHOPCONF.
Strap each driver to match its `uart_address` in `firmware.yaml`, and
note every driver needs a **unique** address:

| Joint | Address | MS1 | MS2 |
| --- | --- | --- | --- |
| base | 0 | GND | GND |
| shoulder | 1 | VIO | GND |
| elbow | 2 | GND | VIO |

Wire GPIO26 through the single 1 kΩ resistor, then bus it to all three
PDN_UART pins tied together. The link is write-only — nothing is read
back, and step/dir remains the only motion path. Two drivers strapped to
the same address will both accept that address's settings and neither
will fault, so a strap mistake shows up as behavior, not an error (see
troubleshooting).

Fallback for reference: if `tmc_uart.enabled` is ever set back to false,
the straps revert to hardware microstep-select (both MS1 and MS2 high =
1/16) and the VREF pot rules current again.

## Flashing the firmware

The firmware builds with PlatformIO (espressif32 + ESP-IDF). Install it if
you don't have it (`pip install platformio`, or the VS Code extension),
then:

```
cd firmware
pio run              # build
pio run -t upload    # flash over USB
pio device monitor   # serial console, 115200 baud
```

Both YAML configs are embedded into the image at build time, so **any change
to `config/firmware.yaml` or `config/robot.yaml` requires a rebuild and
reflash** — but never a code change.

> Note: the firmware builds cleanly but has not yet been run on real
> hardware. Expect to iterate on the datum reference pose and current
> settings during bring-up.

## Bring-up procedure

Work through these stages in order; each one only risks what the previous
stage verified.

The arm has no limit switches, so the datum is set manually with `SETHOME`:
you place the arm at a known reference pose, `ENABLE` so the drivers hold it,
then declare that pose's angles. It stays valid until the next `DISABLE`.

### 1. Smoke test — no motors, no PSU

Flash the ESP32 with nothing but USB connected. In the monitor:

```
PING            → PONG rt-arm-fw 0.1.0
STATE           → current mode / pose / flags
```

If PING answers, the boot chain (config parse, step engine, console) is
alive.

### 2. First power — motors connected, arm NOT assembled

Wire everything, including the PDN_UART bus and the address straps (the
firmware sets motor current at boot — no pots to adjust), and clamp the
motors to the bench (or leave them loose) — do not couple them to the arm
yet.

```
ENABLE          → OK ENABLE      (motors should now hold — try turning a shaft by hand)
DISABLE         → OK DISABLE     (shafts turn freely again)
```

Confirm each motor holds under `ENABLE` and spins freely under `DISABLE`. If a
motor whines but won't hold, or a commanded direction is reversed, note it —
`invert_dir` in `firmware.yaml` fixes direction later.

### 3. Assembled arm — first datum with SETHOME

Mount the motors, couple the gearboxes, and place the arm at your **reference
pose** — a repeatable configuration you can hit accurately, ideally a printed
alignment jig (eyeballing works but the datum is only as good as the
placement). Keep a hand near the PSU switch.

```
ENABLE                       → drivers energize and hold the arm at the placed pose
SETHOME <θ1> <θ2> <θ3>       → EV HOMED manual datum   (angles of your reference pose, deg)
```

`SETHOME` zeroes the step counters to the angles you gave and marks the arm
homed. Re-run it after **every** `DISABLE` — unpowered steppers slip under
gravity, so the datum is dropped on disable by design. Verify it: command a
small move you can eyeball and measure the real angles; if they disagree, your
placement was off — re-place and `SETHOME` again.

### 4. First moves

Moves are refused with `ERR NOT_HOMED` until you `SETHOME` — that's the
firmware protecting you, not a bug.

```
MOVEJ 0 90 -90                → OK MOVEJ T=1.204 STRETCH=1.00 … EV MOVE_DONE
MOVEL 150 0 200               → straight-line move to x/y/z in mm
TELEM 10                      → streams ST pose lines at 10 Hz
STOP                          → halts immediately (also clears FAULT)
```

Every move runs the full twin pipeline on-board (IK, torque retiming,
collision check) — a command the simulator would refuse is refused on
hardware with the same `ERR TORQUE` / `ERR COLLISION` verdict. A
`STRETCH` greater than 1.00 means the torque governor slowed the move to
stay under the torque ceiling; that's normal for aggressive targets.

### 5. Gripper calibration

Do this once, with the arm parked and nothing between the jaws. **Do it against
the Uno alone** — the ESP32 does not need to be powered or even connected, which
is most of the reason the gripper has its own board. The whole model of the
gripper is two pulse widths and the opening they correspond to, all in the
`gripper:` block of `config/firmware.yaml`, and each edit needs a reflash of the
gripper node (`pio run -t upload` in `arduino/gripper_node/`). The shipped values
(1200 / 1800 µs over a nominal 30 mm) are deliberately narrow: a servo driven
past a mechanical stop stalls, draws ~650 mA and strips its own gears within
seconds, so you **widen toward the ends**, never start at them.

Set the bench supply to 5.0 V with a **1 A limit** and leave its current readout
where you can see it. That limit is the safety net for this whole procedure: if
it trips, the pulse span is driving the mechanism into a hard stop, and the fix
is to narrow the calibration rather than push on. Expect roughly 200 mA while
moving.

Open the jaws by hand to `boot_opening_mm` before powering up. The node drives
nothing until its first command, so the jaws will not jump on power-on — but the
first `G` will snap them from the assumed opening to the commanded one.

Talk to it directly over its USB console (`pio device monitor`, 115200):

```
G 0                          → drives to closed_pulse_us
G 30                         → the other end of the calibration
R                            → release; the servo goes slack
```

Or skip the keyboard entirely and sweep the knob — it commands the same axis at
the same slew rate, which is usually the faster way to find where the mechanism
binds. The onboard LED is solid while the jaws hold and blinks while they move.

1. **Find the closed end.** Command `G 0` and watch. If the pads stop short
   of touching, lower `closed_pulse_us` by ~50 µs and reflash; repeat until they
   just meet with no buzz. If the servo grinds, the mechanism visibly strains,
   or the supply's current climbs toward its limit, go back up 50 µs — that is a
   stall, not a grip.
2. **Find the open end.** Command `G <max_opening_mm>` and push
   `open_pulse_us` the same way in ~50 µs steps until the jaws reach their widest
   comfortable opening, again stopping before anything binds.
3. **Measure the stroke.** With the servo holding the open end, measure the
   actual pad-face-to-pad-face gap with calipers and put that number in
   `max_opening_mm`. Every `GRIP` distance is scaled from it.
4. **Check the middle.** Command a few intermediate openings and measure them.
   They should track within a millimetre or so; if they bow consistently, the
   linkage isn't linear over that range and the honest fix is to narrow the
   calibration to the range where it is.
5. **Set the boot opening** to wherever you intend to leave the jaws parked, and
   reflash a last time.

Once the calibration is settled and both boards are wired together, the bundled
script exercises the same openings through the ESP32 and so proves the relay
link end to end:

```bash
python python/run_script.py --port COM5 python/examples/gripper_checkout.txt
```

Keep the Uno's console open while it runs — every command the ESP32 relays is
echoed there, and that echo is the only confirmation the link is alive.

Three things the firmware cannot do for you: it never knows whether the jaws
actually reached the opening it commanded (there is no feedback of any kind), it
cannot tell whether the gripper node is even powered (the link is one-way), and
it does not tell the torque governor that you are now carrying something — send
`PAYLOAD <grams>` yourself after a grasp.

### Command reference

| Command | Arguments | Effect |
| --- | --- | --- |
| `PING` | — | liveness check, returns firmware name/version |
| `STATE` | — | current mode, pose, homed/enabled flags |
| `ENABLE` / `DISABLE` | — | energize / de-energize drivers.**DISABLE drops the homed flag** (unpowered steppers slip under gravity) — re-`SETHOME` after |
| `SETHOME` | θ₁ θ₂ θ₃ (deg) | set the datum — declare the arm's current pose as home. The datum method for this build |
| `HOME` | — | switch-seek homing (needs limit switches —**not fitted on this arm**; use `SETHOME`) |
| `MOVEJ` | θ₁ θ₂ θ₃ (deg) | joint-space move |
| `MOVEL` | x y z (mm) | straight-line Cartesian move via analytic IK |
| `GRIP` | opening mm | jaw opening, pad face to pad face. Relayed to the gripper node; slews at`speed_mm_s`; `EV GRIP_DONE` when it lands. Needs `ENABLE`, not a datum |
| `STOP` | — | immediate halt; clears FAULT |
| `PAYLOAD` | grams | tell the torque governor what the gripper is holding |
| `TELEM` | Hz (0 = off) | telemetry stream rate |

### Running a script of commands

To play back a saved sequence instead of typing commands one at a time, use the
host runner. It reads a `.txt` file of the commands above (one per line; `#`
comments and blank lines ignored; `SLEEP <s>` pauses the host), sends each and
waits for it to finish before the next:

```bash
python python/run_script.py --port COM5 python/examples/demo_moves.txt
```

Its one added behavior: a `MOVEJ` that moves **more than one joint is executed
one joint at a time** (holding the others at their current angle), so the shared
breadboard motor rail only ever powers one moving coil — the fix for the supply
sag when all three drive together. Pass `--no-split` to send coordinated moves
instead. `--dry-run --start θ₁,θ₂,θ₃` previews the exact wire lines (including
the per-joint split) with no hardware attached. `MOVEL` can't be split
host-side (it resolves to a pose on-chip via IK) and is sent whole. Live runs
need `pip install pyserial`.

## Troubleshooting

| Symptom | Likely cause |
| --- | --- |
| Motor whines/holds but won't step | STEP/DIR swapped, or STEP pin miswired |
| Moves land at exactly ½ / 2× / 4× the commanded angle | the UART config never reached that driver (PDN bus wiring, wrong address strap) so it's running its pin-strap default resolution |
| One motor weak/silent while others behave; or two joints act identically | duplicate or wrong MS1/MS2 address straps — each driver needs a unique address (base 0, shoulder 1, elbow 2) |
| Joint moves the wrong direction | flip that joint's`invert_dir` in `firmware.yaml` and reflash |
| `ERR NOT_HOMED` on every move | run`SETHOME` first; also re-`SETHOME` after any `DISABLE` |
| Datum drifts / moves land off by a constant offset | reference-pose placement was inaccurate — re-place the arm and`SETHOME` again (a jig helps) |
| Motors stutter or drivers reset under load | missing VM capacitor, undersized PSU, or missing common ground |
| Skipped steps on fast moves | `irun` too low, or `motor.holding_torque_nm` in `robot.yaml` optimistic — the governor can only respect the torque it's told about |
| ESP32 resets when motors enable | motor PSU current sagging into the USB ground path — check grounding and PSU capacity |
| Jaws jump the moment you send`ENABLE` | the servo is snapping to`gripper.boot_opening_mm` — park the jaws there before power-up, or correct the value and reflash |
| Servo buzzes hard, gets hot, or grinds at one end of the stroke | it is stalled against a mechanical stop — pull`closed_pulse_us`/`open_pulse_us` back toward the middle by ~50 µs and reflash |
| `GRIP 20` doesn't give 20 mm at the pads | calibration:`max_opening_mm` must be the gap you actually measure at `open_pulse_us` |
| Jaws creep open while holding a part | the mechanism is not self-locking and the servo let go — set`release_after_s: 0` (the default) so the PWM never stops |
| Jaws don't move at all,`ERR DISABLED` on GRIP | commands are only relayed after`ENABLE` |
| `GRIP` returns`OK` but nothing moves | the link is one-way, so the ESP32 cannot detect a dead node. Check the Uno's console for the echo, then its power, then the GPIO 13 → D2 wire and the shared ground |
| Uno console shows garbled characters after`ERR BADCMD` | the 3.3 V relay signal has only 0.3 V of margin at the Uno's input — drop`relay_baud` to 9600 and reflash both boards |
| Jaws move on their own during a script | the manual knob took over — it reclaims control whenever it moves past its deadband. Leave it alone, or send another`GRIP` to take control back |
| Bench supply hits its current limit during calibration | the servo is stalled against a stop; narrow`closed_pulse_us`/`open_pulse_us` rather than raising the limit |

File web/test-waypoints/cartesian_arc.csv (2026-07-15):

# cartesian_arc.csv — happy path: Cartesian (IK) mode
# Semicircular sweep | radius 150mm | fixed height z=150mm | base yaw -120..120 deg.
# All points comfortably within reach (240mm) and joint limits; use with
# "Cartesian (IK)" mode selected in the Pose command panel.
x | y | z
-75.0 | -129.9 | 150
0 | -150 | 150
75.0 | -129.9 | 150
129.9 | -75.0 | 150
150 | 0 | 150
129.9 | 75.0 | 150
75.0 | 129.9 | 150
0 | 150 | 150
-75.0 | 129.9 | 150

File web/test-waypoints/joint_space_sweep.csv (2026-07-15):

# joint_space_sweep.csv — Joint space mode
# theta1 | theta2 | theta3 (deg). A smooth open sweep across most of each joint's
# range | followed by a base-limit violation (140 > 135 max) and an
# extreme fold that should trip the self/ground collision check.
# Expect 8 waypoints loaded | 2 skipped.
theta1 | theta2 | theta3
0 | 90 | 0
20 | 80 | 20
40 | 70 | 40
60 | 60 | 60
80 | 50 | 80
100 | 40 | 100
120 | 30 | 120
135 | 20 | 140
140 | 20 | 140
0 | 0 | 150

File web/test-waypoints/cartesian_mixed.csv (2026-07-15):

# cartesian_mixed.csv — parser stress test: Cartesian (IK) mode
# Exercises: leading header tolerance | comma/tab/semicolon delimiters
# an unreachable point | a collision near the base column | and two
# malformed rows. Expect 4 waypoints loaded | 4 skipped.
x | y | z (mm)
150 | 0 | 150
0 150 150
-75; 129.9; 150
1000 | 1000 | 1000
15 | 0 | 50
50 | 50
abc | 50 | 50
-129.9 | 75 | 150

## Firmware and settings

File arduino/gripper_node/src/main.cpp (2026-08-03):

// RobotTwin gripper node — an Arduino Uno driving the SG-90 parallel-jaw
// gripper, independent of the ESP32 that runs the arm.
//
// Why this board exists: a stalled SG-90 pulls ~650 mA, which is exactly the
// transient that browns out a board generating step pulses, and a hobby servo
// wants 5 V logic rather than the ESP32's marginal 3.3 V. The gripper was
// always the least-coupled part of the robot — no kinematics, no trajectory, no
// homing, no torque governor — so it costs nothing to give it its own board and
// its own supply. See docs/wiring-and-bringup.md.
//
// Two ways to command it, whichever moved last wins:
//   - the knob on the analog pin, which needs no computer at all and is how
//     the mechanism gets calibrated;
//   - "G <mm>" / "GRIP <mm>" on either serial port — USB from a host, or the
//     one-way relay from the ESP32 so scripted moves can grip mid-sequence.
//
// The slew rate limiting and the opening → pulse width mapping are NOT written
// here. They come from rt::GripperAxis, the same class the twin and the ESP32
// use, from the same calibration in config/firmware.yaml. That is what lets the
// ESP32 predict when the jaws land without ever hearing back from this board.

#include <Arduino.h>
#include <Servo.h>
#include <SoftwareSerial.h>

#include "gripper_config_gen.hpp"
#include "hardware/gripper.hpp"

namespace {

constexpr rt::GripperConfig kCfg = rt::kGripperConfig;

Servo servo;
rt::GripperAxis axis;

// D3 is not wired to anything yet — SoftwareSerial demands a TX pin, and this
// reserves the one the return path would use if this link ever grows one.
constexpr uint8_t kUnusedTxPin = 3;
SoftwareSerial relay(kCfg.relayRxPin, kUnusedTxPin);

// ---- control cadence -------------------------------------------------------
// 200 Hz: four times the servo's own frame rate, so the slew is smooth, while
// each dt stays large enough to accumulate cleanly in AVR's 32-bit double.
constexpr unsigned long kTickIntervalUs = 5000UL;
unsigned long lastTickUs = 0;

// ---- knob ------------------------------------------------------------------
// A raw ADC reading jitters by a count or two forever, which would let the knob
// silently steal control back from a script. So the knob only takes over once
// it moves decisively away from where it sat when the last serial command
// arrived; a serial command then re-anchors it and reclaims control.
constexpr int kKnobDeadband = 8;   // of 1023
constexpr int kAdcMax = 1023;
int knobAnchor = -1;
bool knobOwns = false;

// ---- drive state -----------------------------------------------------------
// Nothing is driven at boot. The jaws are only assumed to be at
// boot_opening_mm, so snapping to a knob or a stale target on power-up would
// lurch the mechanism; the first deliberate command is what energizes it.
bool energized = false;
double commanded = -1;  // m — last value handed to the axis, to avoid re-arming

// ---- line assembly ---------------------------------------------------------
constexpr uint8_t kLineMax = 24;
char usbLine[kLineMax];
uint8_t usbLen = 0;
char relayLine[kLineMax];
uint8_t relayLen = 0;

/** Hand a new destination to the axis, but only if it is actually new. */
void command(double openingM) {
  // setOpening() re-arms the idle timer on every call, so calling it every tick
  // with an unchanged value would defeat release_after_s entirely.
  if (commanded >= 0 && fabs(openingM - commanded) < 1e-5) return;
  if (!axis.setOpening(openingM)) return;  // out of range; leave the jaws alone
  commanded = openingM;
  energized = true;
}

/** Stop driving: the servo goes slack and the signal line idles. */
void release() {
  energized = false;
  commanded = -1;
  if (servo.attached()) servo.detach();
}

/**
 * Handle one received line. Accepts "R" plus "G <mm>" and its long spelling
 * "GRIP <mm>", so the ESP32's terse relay frames and a human at a serial
 * monitor can use the same parser.
 */
void handleLine(char* line, Stream& echo) {
  while (*line == ' ') ++line;
  if (*line == '\0') return;

  if (line[0] == 'R' && (line[1] == '\0' || line[1] == ' ')) {
    release();
    echo.println(F("R"));
    return;
  }

  char* arg = nullptr;
  if (strncmp(line, "GRIP", 4) == 0) {
    arg = line + 4;
  } else if (line[0] == 'G') {
    arg = line + 1;
  }
  // The separator is required, so a bare "G" is a malformed command rather than
  // a silent "close fully" — atof() would happily read the empty string as 0.
  if (arg == nullptr || *arg != ' ') {
    echo.print(F("ERR BADCMD "));
    echo.println(line);
    return;
  }
  while (*arg == ' ') ++arg;
  // Likewise reject anything atof() would quietly turn into 0.
  if (*arg != '.' && (*arg < '0' || *arg > '9')) {
    echo.print(F("ERR BADCMD "));
    echo.println(line);
    return;
  }

  const double mm = atof(arg);
  if (mm < 0 || mm > kCfg.maxOpening * 1000.0) {
    echo.print(F("ERR RANGE "));
    echo.println(mm);
    return;
  }
  command(mm / 1000.0);
  knobOwns = false;              // a command outranks the knob...
  knobAnchor = analogRead(kCfg.knobPin);  // ...until the knob moves again
  echo.print(F("G "));
  echo.println(mm);
}

/** Accumulate bytes into `buf` and dispatch on newline. */
void pump(Stream& port, char* buf, uint8_t& len, Stream& echo) {
  while (port.available() > 0) {
    const char c = static_cast<char>(port.read());
    if (c == '\n' || c == '\r') {
      if (len > 0) {
        buf[len] = '\0';
        handleLine(buf, echo);
        len = 0;
      }
      continue;
    }
    // A line this long is noise on the wire, not a command — drop it rather
    // than let a stuck sender wedge the buffer forever.
    if (len >= kLineMax - 1) {
      len = 0;
      continue;
    }
    buf[len++] = c;
  }
}

void pollKnob() {
  const int raw = analogRead(kCfg.knobPin);
  if (knobAnchor < 0) {
    knobAnchor = raw;  // first reading is the reference, not a movement
    return;
  }
  if (!knobOwns && abs(raw - knobAnchor) > kKnobDeadband) knobOwns = true;
  if (!knobOwns) return;

  knobAnchor = raw;
  command(static_cast<double>(raw) / kAdcMax * kCfg.maxOpening);
}

/** Solid while holding, blinking while the jaws are moving, off when slack. */
void updateLed(bool driving) {
  if (!driving) {
    digitalWrite(LED_BUILTIN, LOW);
    return;
  }
  if (!axis.moving()) {
    digitalWrite(LED_BUILTIN, HIGH);
    return;
  }
  digitalWrite(LED_BUILTIN, (millis() / 100) % 2 == 0 ? HIGH : LOW);
}

}  // namespace

void setup() {
  Serial.begin(115200);
  relay.begin(kCfg.relayBaud);
  axis.init(kCfg);
  pinMode(LED_BUILTIN, OUTPUT);
  digitalWrite(LED_BUILTIN, LOW);
  lastTickUs = micros();

  Serial.println(F("RobotTwin gripper node"));
  Serial.print(F("max opening mm: "));
  Serial.println(kCfg.maxOpening * 1000.0);
  Serial.println(F("commands: G <mm> | GRIP <mm> | R"));
}

void loop() {
  // Serial and the knob are polled every pass so the node stays responsive;
  // only the slew itself runs on the fixed tick.
  pump(Serial, usbLine, usbLen, Serial);
  pump(relay, relayLine, relayLen, Serial);  // relay traffic echoes to USB
  pollKnob();

  const unsigned long now = micros();
  if (now - lastTickUs < kTickIntervalUs) return;
  const double dt = static_cast<double>(now - lastTickUs) * 1e-6;
  lastTickUs = now;

  axis.advance(dt);

  // release_after_s is honoured locally, so a knob-only bench session still
  // stops the servo buzzing once the jaws settle.
  const bool driving = energized && axis.driving();
  if (driving) {
    if (!servo.attached()) servo.attach(kCfg.pin);
    servo.writeMicroseconds(static_cast<int>(axis.pulseWidth() * 1e6 + 0.5));
  } else if (servo.attached()) {
    servo.detach();
  }
  updateLed(driving);
}

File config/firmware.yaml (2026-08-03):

# RobotTwin — firmware/electronics parameters (ESP32 + 3x TMC2209).
# Companion to robot.yaml: that file describes the robot, this file describes
# the controller wired to it — pins, homing, control rates, safety margins.
# Embedded into the firmware image at build time and parsed at boot, so a pin
# change is a config edit + reflash, never a code change.
#
# Pin defaults target a plain ESP32 DevKit (WROOM-32). Constraints honored:
#   - step/dir/enable pins must be < GPIO32 (ISR uses the low GPIO bank)
#   - strapping pins (0, 2, 5, 12, 15) and input-only pins (34-39) avoided
# Homing values are bring-up placeholders — finalize against the real arm.

firmware:
  name: rt-arm-fw

serial:
  baud: 115200
  telemetry_hz_default: 0    # ST lines per second at boot (0 = off, TELEM enables)

control:
  loop_hz: 1000              # trajectory-following / homing state machine rate
  step_tick_hz: 40000        # step-generator ISR rate; also the max step rate

safety:
  torque_ceiling: 0.90       # retime moves until peak utilization <= this
  max_stretch: 32            # give up (reject move) beyond this duration multiplier
  min_move_duration_s: 0.25
  homing_timeout_s: 30       # per-joint seek watchdog

driver_enable:               # one EN line shared by all three TMC2209s
  pin: 23
  active_low: true

# Single-wire UART to the TMC2209s — ENABLED: boot programs microstepping
# (CHOPCONF, from robot.yaml motor.microstepping) and run/hold current
# (IHOLD_IRUN) into each driver, so the VREF pots are ignored. TX runs
# through a 1k resistor to the shared PDN_UART line; drivers are addressed
# by their MS1/MS2 straps (base 0, shoulder 1, elbow 2 — see uart_address
# per joint). Write-only: nothing is read back; step/dir stays the only
# motion path. If ever set back to false, the MS1/MS2 straps revert to
# microstep-select and MUST match robot.yaml by wiring.
tmc_uart:
  enabled: true
  tx_pin: 26
  baud: 115200
  # ~0.9-1.0 A RMS with typical 110 mOhm sense. Dropping to 12 to chase rail
  # sag cost ~25% torque and left the shoulder at only x1.6 gravity margin --
  # it clicked (skipped poles) trying to lift. Torque is the binding constraint
  # here, not current draw, so this stays at 16.
  irun: 16                   # run current scale 0..31 (31 = full scale)
  # Standstill current. At 8 the shoulder held only ~1.0x its own gravity
  # torque through the 15:1 and backdrove ("flopped") the moment a move ended
  # and current dropped from irun. 14 restores ~1.8x. NOTE: ihold is drawn
  # CONTINUOUSLY while enabled -- this exceeds the breadboard's comfortable
  # budget, so DISABLE between tests and touch-check the drivers for heat
  # until the motor supply moves to soldered joints or screw terminals.
  # Held at parity with irun so the shoulder holds the pose it just moved to --
  # at 8 it backdrove ("flopped") the instant a move ended and current dropped.
  ihold: 16                  # standstill current scale 0..31

# Gripper axis — the SG-90 hobby servo driving the parallel-jaw mechanism at
# the forearm tip. Nothing like the three joints: no driver, no step/dir, no
# homing, no torque governor. One 50 Hz PWM channel whose pulse width sets the
# jaw opening, and the two calibration pulses below ARE the entire model —
# opening is assumed linear between them, which is what a rack-and-pinion (or
# the equivalent geared parallel linkage) gives over its usable swing.
#
# THE SERVO DOES NOT RUN ON THE ESP32. An Arduino Uno drives it from its own
# 5 V bench supply, so a ~650 mA stall transient cannot brown out the board that
# is generating step pulses, and the servo sees proper 5 V logic instead of the
# ESP32's marginal 3.3 V. The ESP32 only relays "G <mm>" over a one-way serial
# link. Both boards read this same block: the ESP32 through the usual embedded
# YAML, the Uno through arduino/gripper_node/scripts/gen_gripper_config.py.
# That is why pin numbers for two different boards live side by side below.
#
# CALIBRATE BEFORE TRUSTING THESE NUMBERS. The pulse span starts deliberately
# narrow so a first power-on cannot drive the mechanism into its hard stops and
# stall the servo (a stalled SG-90 draws ~650 mA and cooks its gears). Widen
# closed/open a little at a time with GRIP while watching the jaws, then set
# max_opening_mm to the opening you actually measure at open_pulse_us.
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

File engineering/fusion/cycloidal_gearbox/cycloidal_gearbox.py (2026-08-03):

"""RobotTwin — cycloidal gearbox generator for Autodesk Fusion (v3, pinned
two-part casing).

Generates two single-stage cycloidal gearbox cartridges — 15:1 and 20:1 —
driven entirely by engineering/gearboxes/gear_parameters.yaml, and exports
them per part to engineering/gearboxes/15_1/ and 20_1/:

    rt_cyc<N>_cup     — back casing half: motor plate + Ø76 outer wall.
                        The NEMA 17 bolts to its back (pilot recessed).
    rt_cyc<N>_lid     — front casing half: Ø76 annular flange whose face
                        seats on the linkage ear disc; the output's
                        extension passes out through its face bore.
    rt_cyc<N>_disc    — cycloid disc (x2 per gearbox, cam lobes 180° apart)
    rt_cyc<N>_cam     — eccentric input cam on the motor's 5 mm D-shaft
    rt_cyc<N>_output  — output flange: six Ø6 x 25 steel dowels reach back
                        through the discs; the Ø22 hub continues past the
                        lid face as the SHAFT-CLAMP EXTENSION (live-shaft
                        v5): a Ø25.05 seat for the drive ear's 6805, then
                        a Ø24.6 split pinch that clamps the 8 mm shaft.

v3 design intent (after the v2 print failed): SIMPLE. The casing is two
flat, support-free prints held together — and registered — by the Zp ring
dowels themselves: each Ø6 x 25 pin runs through the entire cup (press
holes, flush at the back face) and 6.5 mm into a blind hole in the lid, so
every pin is loaded in double shear and is fully captive once the halves
meet. Six M3 x 40 screws from the gearbox back clamp cup + lid + ear disc
in one stack (they are both the case closure and the mounting), which is
also why the casing can be a plain Ø76 cylinder: no driver has to sneak
past the Ø66 bolt circle any more, so the v2 necks, grooves, slits, and
pinch-access tunnels are all gone.

The discs get a Ø62.5 interior — over 4 mm of radial air to the box; the
mesh happens ONLY on the free-standing pins, and the hobbed profile now
carries 0.25 mm radial print clearance (yaml-tunable — the 0.15 of v2
printed too tight). python/validate_cycloid.py additionally sweeps the
assembled mesh through a full cam revolution and reports the running
clearance so a jam is caught numerically, not at the printer.

Interface to the linkage (live-shaft v5, matching the pinch-hub arms): Ø76
ear disc face, 6 x M3 heat-set inserts on a Ø66 bolt circle. The 8 mm
joint shaft IS the torque path: it slips into the output's Ø8.35 bore
(reaching inside the casing to z 28) and the extension's split pinch
clamps it; at the far end the arm hub's own pinch grabs it, so torque
flows output -> shaft -> arm. The extension carries a Ø25.05 seat for the
6805 bearing housed in the drive ear — that bearing, plus the 608 in the
+Y ear, carries the structural joint loads. The lid's face bore is pure
pass-through (Ø = seat + 0.8, so the extension assembles through it — the
old Ø23 hub journal could never pass the Ø25.05 seat and is gone). The
shaft stays smooth (no flat): both couplings are press bores closed by
pinch bolts.

Z axis = gearbox axis; z = 0 is the back face the NEMA 17 bolts to;
z = BODY_L is the lid face that seats on the linkage ear disc.

Run from Fusion: UTILITIES > ADD-INS > Scripts and Add-Ins > "+" > select
this folder > Run. Direct modeling, no timeline: edit the yaml and re-run.
The hobbing cuts take a minute or two — Fusion is not hung.

Run from a shell (no Fusion) for a dry run of the parameters and the
derived stack:  python cycloidal_gearbox.py
"""

import math
import os
import re
import traceback

try:
    import adsk.core
    import adsk.fusion
    IN_FUSION = True
except ImportError:
    IN_FUSION = False

# ---------------------------------------------------------------------------
# Standard purchased hardware and print constants (mm). Everything specific
# to THIS gearbox design lives in gear_parameters.yaml, not here.
# ---------------------------------------------------------------------------

# NEMA 17 (17HS4401), mounted directly on the cup's back plate
NEMA_HOLE_SPACING = 31.0
NEMA_PILOT_D = 22.5             # pilot boss + clearance
NEMA_PILOT_H = 2.2              # recess depth (boss is 2.0)
NEMA_BORE_D = 14.0              # shaft + boss shoulder clearance through the plate
MOTOR_SHAFT_D = 5.0             # D-shaft: Ø5, flat leaves 4.5 (plane at x = 2.0)
MOTOR_FLAT_X0 = 2.0             # cam D-bore fit is yaml (motor_*_clearance)
NEMA_SHAFT_LEN_MAX = 25.0       # above the mounting face (measured 23.5)

# 6802-2RS (15 x 24 x 5), one per disc, on the eccentric cam journals
ECC_BRG_BORE = 15.0
CAM_JOURNAL_D = ECC_BRG_BORE + 0.05     # light press after printing

# Linkage-side joint contract (mirror of the constants in
# engineering/fusion/robot_linkages/linkage_geometry.py — keep in sync).
# The output extension crosses the drive ear (through its 6805) and ends in
# the split pinch that clamps the live shaft, one running gap shy of the
# arm hub's face.
EAR_T = 12.0                    # drive-ear thickness (6805 pocket + shoulder)
JOINT_GAP = 0.75                # running gap each side of the pinch section

# 6805-2RS (25 x 37 x 7): drive-ear support bearing on the extension's seat
EAR_BRG_BORE = 25.0
EAR_BRG_W = 7.0

# M3 fasteners
M3_CLEAR_D = 3.4
M3_NUT_AF = 5.5                 # across flats
M3_NUT_T = 2.4
M3_CB_D = 6.0                   # socket-head counterbore (5.5 head): kept tight
                                # because the ring-pin holes pass close by at R 28
M3_CB_FLOOR = 1.5               # web left under the motor screw heads
M3_HEAD_D = 5.5
M3_HEAD_H = 3.0
MOUNT_CB_D = 6.5                # mount-screw counterbore in the cup back
MOUNT_CB_T = 2.0                # its depth (sets insert engagement ~6 mm)

GAP = 0.5                       # default axial running gap
MIN_WALL = 1.6                  # printable-wall floor (4 perimeters at 0.4 mm)
HOB_STEPS_PER_LOBE = 32         # cutter positions per lobe (envelope err < 0.01)
BUILD_VOLUME = 180.0            # Bambu Lab A1 Mini


# ---------------------------------------------------------------------------
# Parameters — engineering/gearboxes/gear_parameters.yaml is the only source.
# Minimal two-level 'Section: / key: number' parser (Fusion has no PyYAML).
# ---------------------------------------------------------------------------

def yaml_path():
    here = os.path.dirname(os.path.abspath(__file__))
    return os.path.abspath(os.path.join(
        here, '..', '..', 'gearboxes', 'gear_parameters.yaml'))
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

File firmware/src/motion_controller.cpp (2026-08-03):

#include "motion_controller.hpp"

#include <cmath>
#include <cstdio>

#include "driver/gpio.h"
#include "esp_timer.h"
#include "freertos/task.h"

#include "drivetrain/drivetrain.hpp"
#include "geometry/collision.hpp"
#include "kinematics/kinematics.hpp"
#include "math/units.hpp"
#include "planning/retime.hpp"
#include "simulation/metrics.hpp"

namespace fw {

namespace {

using rt::proto::reason::kBusy;
using rt::proto::reason::kCollision;
using rt::proto::reason::kDisabled;
using rt::proto::reason::kFault;
using rt::proto::reason::kLimits;
using rt::proto::reason::kNotHomed;
using rt::proto::reason::kTorque;
using rt::proto::reason::kUnreachable;

// Mirrors SPEED_PLANNING_MARGIN in web/src/state/store.ts: plan below the
// hard drivetrain ceilings so torque utilization stays finite.
constexpr double kSpeedPlanningMargin = 0.8;

// Extra tracking rate over the sampled velocity so the DDA absorbs target
// quantization and tick jitter instead of falling behind the profile.
constexpr double kRateMargin = 1.25;
constexpr double kRateFloorStepsPerS = 50.0;

// Rate used to close the last rounding step or two after a profile ends.
constexpr double kSettleRateStepsPerS = 200.0;

CmdResult err(const char* reason, std::string detail) {
  CmdResult r;
  r.ok = false;
  r.reason = reason;
  r.detail = std::move(detail);
  return r;
}

}  // namespace

void MotionController::init(const rt::RobotConfig& robot, const rt::HardwareConfig& hw,
                            StepEngine& steps) {
  robot_ = robot;
  hw_ = hw;
  steps_ = &steps;
  payload_ = robot.masses.payloadDefault;

  for (int j = 0; j < rt::kNumJoints; ++j) {
    stepsPerRad_[j] = 1.0 / rt::jointResolution(robot.motor, robot.gearboxes[j]);

    const auto& lim = hw.joints[j].limit;
    const auto pin = static_cast<gpio_num_t>(lim.pin);
    gpio_reset_pin(pin);
    gpio_set_direction(pin, GPIO_MODE_INPUT);
    gpio_set_pull_mode(pin, lim.activeLow ? GPIO_PULLUP_ONLY : GPIO_PULLDOWN_ONLY);
  }

  grip_.init(hw.gripper);
  gripLink_.init(hw.gripper);
  gripOpening_ = hw.gripper.bootOpening;
  gripRequest_ = hw.gripper.bootOpening;

  events_ = xQueueCreate(8, sizeof(Event));

  // Core 1 keeps the 1 kHz cadence away from the main (console/planning) task.
  const auto entry = [](void* self) { static_cast<MotionController*>(self)->controlTask(); };
  xTaskCreatePinnedToCore(entry, "rt_control", 6144, this, 10, nullptr, 1);
}

// ---------------------------------------------------------------- commands

CmdResult MotionController::enable() {
  steps_->setEnabled(true);
  // The servo has no enable line of its own, so ENABLE is also what starts
  // relaying commands to it. It snaps to the last commanded opening, which
  // after a boot or a DISABLE is an assumption (gripper.boot_opening_mm) rather
  // than a measurement — park the jaws there before powering up.
  portENTER_CRITICAL(&mux_);
  gripDriven_ = true;
  gripFreeze_ = true;  // hold the current opening, and re-arm release_after_s
  portEXIT_CRITICAL(&mux_);
  return {};
}

CmdResult MotionController::disable() {
  // De-energized steppers can slip (gravity backdrives the pitch joints), so
  // the position datum is no longer trustworthy: require a re-home.
  portENTER_CRITICAL(&mux_);
  steps_->haltAll();
  if (mode_ != Mode::Fault) mode_ = Mode::Idle;
  homed_ = false;
  gripDriven_ = false;  // nothing on the robot stays energized after DISABLE
  gripFreeze_ = true;   // …and a slack servo is not slewing anywhere
  gripPending_ = false;
  portEXIT_CRITICAL(&mux_);
  steps_->setEnabled(false);
  return {};
}

CmdResult MotionController::stop() {
  // Also the fault-recovery verb: freeze everything, back to IDLE.
  portENTER_CRITICAL(&mux_);
  steps_->haltAll();
  gripFreeze_ = true;  // jaws hold where they are; STOP must not drop a part
  gripPending_ = false;  // …including a GRIP that raced the STOP
  mode_ = Mode::Idle;
  portEXIT_CRITICAL(&mux_);
  return {};
}

CmdResult MotionController::home() {
  CmdResult r;
  if (!guard(r, /*needHomed=*/false)) return r;

  portENTER_CRITICAL(&mux_);
  homed_ = false;
  homingIdx_ = 0;
  phase_ = HomePhase::SeekFast;
  phaseEntered_ = false;
  jointStartUs_ = esp_timer_get_time();
  mode_ = Mode::Homing;
  portEXIT_CRITICAL(&mux_);
  return {};
}

CmdResult MotionController::setHome(const rt::JointAngles& q) {
  CmdResult r;
  if (!guard(r, /*needHomed=*/false)) return r;

  // Manual datum: the operator has physically placed the arm at q right now
  // (a jig or an eyeballed reference pose), so zero the step counters to it
  // and declare homed. This is the switchless answer for an arm with no
  // endstops — the datum is exactly as accurate as the placement. Requires
  // ENABLE first (the drivers must be holding the jigged pose), and must be
  // re-run after any DISABLE, which drops the datum because unpowered
  // steppers slip. Angles must be inside the joint limits.
  for (int j = 0; j < rt::kNumJoints; ++j) {
    const auto& lim = robot_.limits[j];
    if (q[j] < lim.min || q[j] > lim.max)
      return err(kLimits, std::string(rt::jointName(static_cast<rt::Joint>(j))) +
                              " outside joint limits");
  }

  portENTER_CRITICAL(&mux_);
  for (int j = 0; j < rt::kNumJoints; ++j) steps_->setPosition(j, radToSteps(j, q[j]));
  homed_ = true;
  mode_ = Mode::Idle;
  portEXIT_CRITICAL(&mux_);

  postEvent("HOMED", "manual datum");
  return {};
}

CmdResult MotionController::moveJoints(const rt::JointAngles& q) {
  CmdResult r;
  if (!guard(r, /*needHomed=*/true)) return r;

  for (int j = 0; j < rt::kNumJoints; ++j) {
    const auto& lim = robot_.limits[j];
    if (q[j] < lim.min || q[j] > lim.max)
      return err(kLimits, std::string(rt::jointName(static_cast<rt::Joint>(j))) +
                              " outside joint limits");
  }
  const auto pose = rt::checkPose(q, robot_.links, robot_.collision);
  if (pose.colliding) return err(kCollision, rt::describe(pose.issues[0]));

  return planAndStart(q);
}
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

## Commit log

2026-07-13 Gear Selector
    [robot.yaml]
2026-07-13 feat(core): complete C++20 core library with WASM bridge and interactive digital twin
    Implement Phase 2–3 hybrid: full robotics mathematics library (kinematics, dynamics,
    planning, collision detection) in C++20 with modern tooling (CMake/MSVC), paired with
    identical TypeScript mirror for browser compatibility. WASM integration via emscripten
    embind exposes core to React frontend. Interactive twin lets users explore gearbox
    configurations in real-time: analytical FK/IK (4 branches), Jacobian, stepper+gearbox
    torque budgets, quintic trajectory planning with plan-time skipped-step prediction, CSV
    waypoint sequences, and collision-aware path validation. Unit tests in both C++ (ctest)
    and TypeS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
    [robot.yaml]
2026-07-13 fix: resolve WASM initialization race condition and expose missing ratioRange API
    Fixed a race condition where React components tried to use WASM functions before
    the module finished loading. Deferred store initialization and added async
    loading state in App.tsx. Added missing ratioRange() function to WASM bindings
    to support gearbox ratio validation.
    Also updated gearbox efficiency assumptions: planetary 75% (down from 88%),
    cycloidal 60% (down from 75%) based on empirical estimates.
    [robot.yaml]
2026-07-13 feat(web): add torque governor that retimes moves
    Stretch each planned move's duration (exponential search + bisection)
    until the predictive torque audit fits a 95% utilization ceiling, so a
    commanded move can never exceed the torque limit. Surface the applied
    stretch in the Last move panel; the skipped-steps warning now only
    fires on static overload, which no timing can fix.
2026-07-13 feat(cad): add Fusion API generator for rigid linkages
    Generates the four printed members (base pan, yaw column, upper arm,
    forearm) from config/robot.yaml geometry and exports f3d/step/stl into
    engineering/. Joints follow the project architecture: 608 bearings in
    clevis ears carry structural loads, 8 mm shafts with collar locks carry
    torque, and each pitch joint reserves a Ø66x24 cycloidal gearbox
    envelope with a NEMA 17 mount (gearbox design itself out of scope).
    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
2026-07-13 fix(cad): don't rename root component of unsaved doc
2026-07-13 feat(cad): M3 heat-set inserts + direct-drive base
    All fasteners are M3; printed members carry O4.6x6.5 insert pockets
    wherever parts bolt to them (column coupling, hub flanges, T8 plate).
    The base joint is direct-driven: the NEMA 17 stands through the pan
    floor with its face on a 2 mm web under the top plate, and the yaw
    column bolts onto a 5 mm flange shaft hub at the shaft tip. robot.yaml
    base drive default updated to direct/1 to keep the twin consistent
    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
    [robot.yaml, rt-arm-3dof_linkages.f3d, rt-arm-3dof_linkages.step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]
2026-07-13 feat(cad): printed split-clamp coupling + yaw bearing
    Replace the set-screw flange hub with a printable split-clamp coupling
    (rt_shaft_coupling, its own component/STEP): 5 mm D-bore clamp with two
    M3 cross-bolts, O25 journal, O30 insert flange. A 6805-2RS on the
    journal seats in a legged boss on the pan, taking the arm weight and
    moment off the bare motor shaft (loads pass in compression through the
    web into the motor face). STEP export is now one file per part.
    [608-2rs.STEP, rt-arm-3dof_linkages.f3d, rt-arm-3dof_linkages.step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]
2026-07-13 chore(cad): file coupling STEP with standard parts
    Also drop the combined-assembly STEP: exports are one file per part.
    [rt-arm-3dof_linkages.step]
2026-07-15 Cycloidal gears + quadrants for the digital twin
    [6805-2rs.STEP, cartesian_arc.csv, cartesian_mixed.csv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]
2026-07-19 feat(firmware): ESP32 controller with TMC2209 drivers and planning pipeline
    Complete firmware implementation for the ESP32 DevKit controlling three NEMA 17
    steppers via TMC2209 drivers. The firmware embeds the robot kinematics, dynamics,
    and planning pipeline from the core C++ library, running all motion validation
    on-chip: forward/inverse kinematics, speed limiting, torque governance, collision
    checking, and quintic trajectory planning. Hardware configuration (pin map,
    homing parameters, safety limits) is stored in firmware.yaml, parsed at boot,
    and never requires code changes.
    Architecture:
    - 40 kHz step ISR for integer DDA step generation
    - 1 kHz control loop running the motion controlle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
    [firmware.yaml, main.cpp, motion_controller.cpp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]
2026-07-21 feat(firmware): SETHOME manual datum + GPIO4/27 for base joints
    - Add SETHOME command: operator places arm at known pose, declares angles,
    firmware zeros step counters to them and marks homed. No switches needed.
    Validating against joint limits; re-run after DISABLE (steppers slip).
    - Relocate base joint from GPIO16/17 (missing on 30-pin boards) to GPIO4
    (STEP) and GPIO27 (DIR). Also rewritten docs/breadboard-wiring.md to
    reference the new pins. Firmware config updated; host test adjusted.
    - Switch-seek HOME command left intact for future users who fit switches.
    - Protocol tests (SETHOME parse/arity/verb) + firmware SETHOME
    implementation + console dispatch all verified on host bui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
    [firmware.yaml, motion_controller.cpp, motion_controller.hpp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]
2026-07-21 docs(wiring): remove limit switches from the wiring guides
    The arm has no limit switches designed in and no hard stops to mount
    them against; the datum is set with SETHOME. Stop instructing wiring of
    three nonexistent switches: drop them from the parts lists, pin map,
    ASCII diagram, breadboard net list, the dedicated Limit switches
    section, and the bring-up stages (now ENABLE -> SETHOME). GPIO32/33/25
    freed. Switch-seek HOME left in the command reference, marked not
    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
2026-07-22 fix(firmware): embed configs via build-time codegen
    ESP-IDF EMBED_TXTFILES in the component CMakeLists made PlatformIO's
    SCons import mis-map the generated robot.yaml.S into a doubled build
    path (.pio/build/esp32dev/.pio/build/esp32dev/...), so the firmware
    never actually built under PlatformIO.
    Generate src/embedded_yaml_gen.hpp from config/*.yaml via a pre-build
    hook (scripts/gen_embedded_configs.py); embedded_configs.cpp includes
    it instead of the asm _binary_ symbols. Same YAML baked into flash,
    regenerated every build.
    Also track src/hardware/hardware_config.* (compiled by the firmware
    component but never committed) and ignore .pio/ + the generated header.
    Verified: clean build green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
    [hardware_config.cpp]
2026-07-22 docs(bringup): add breadboard guide and handoff
    Add breadboard-step-by-step.md: a hole-by-hole bench-wiring guide for
    the dovetailed two-board layout, locked to the ELEGOO DevKit V1 TypeC,
    with multimeter verification gates (VM-to-3V3 open; staged power-up with
    drivers removed) after a driver rig killed a board.
    Add HANDOFF.md capturing bring-up status.
    Corrections to the existing guides: PDN two-pad note fixed for split
    TX/RX carriers (bus goes to RX, write-only); drop the wrong claim that
    the 30-pin ELEGOO lacks GPIO16/17. Cross-links added.
2026-08-02 feat(twin): add commandable move program
    The twin had no way to command a sequence of moves: dragging a slider
    made the arm follow the cursor, unlike the physical robot, which drains
    a queue of moves one at a time. Sliders now pose the arm; the program
    commands it.
    Each row is a Cartesian target (mm, solved by IK with branch continuity)
    or a joint target (deg), plus a dwell and an enable flag. Rows resolve as
    they are typed, so reach, joint-limit and collision failures are shown
    per row instead of being dropped silently. Running commits a resolved
    snapshot, matching the firmware's contract that a queued move is fixed
    once accepted; mid-run edits apply to the next run. Supports run, pause,
    r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
2026-08-02 feat(twin): add polar move rows to the program
    Program rows could be Cartesian or joint space; add polar (cylindrical
    r, theta, z about the base yaw axis) as a third frame.
    Polar is the arm's natural frame -- FK is tcp = (r*cos01, r*sin01, z) --
    so r is planar reach, theta is the base angle, and z is height. Sweeping
    the base at fixed radius is one number here against two coupled ones in
    Cartesian. Positional rows share a single path: polar converts to
    Cartesian, then both go through the same IK, limit and collision gates.
    The row badge cycles Cartesian -> polar -> joint and keeps the typed
    numbers rather than converting them, since the three frames measure
    different quantities. CSV gains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
2026-08-03 gripper code
    [Robot_Assembly.SLDASM, robot.yaml, rt-arm-3dof_linkages.f3d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]
